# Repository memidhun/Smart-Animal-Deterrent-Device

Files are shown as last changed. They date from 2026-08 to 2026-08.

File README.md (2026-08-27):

# Automated Wildlife Monitoring & Deterrent System





An end-to-end, edge-AI powered wildlife monitoring and eco-friendly deterrence solution designed for forest-edge and agricultural borders. The system uses edge-optimized deep learning to detect wild animals in real time and triggers a non-lethal acetylene-gas combustion deterrent alongside long-range LoRa alerts.
<div align="center">
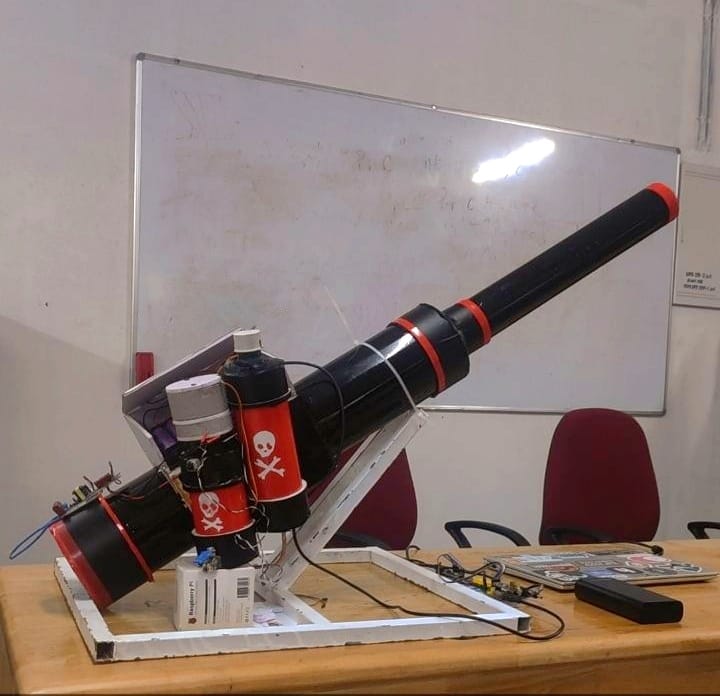
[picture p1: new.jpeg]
Prototype-Image
  
</div>

## Technical Highlights

* **Edge AI & Computer Vision:** Customs-trained **LoRa11n** (optimized YOLOv11n) running locally via NCNN engine on Raspberry Pi 4B.

* **Long-Range Wireless Stack:** Off-grid RF alerts over 3–5 km using LoRa SX1278 modules.

* **Automated Physical Deterrent:** Chemically generated Acetylene gas ($\text{CaC}_2 + 2\text{H}_2\text{O} \rightarrow \text{C}_2\text{H}_2 + \text{Ca(OH)}_2$) ignited via high-voltage spark to produce high-decibel acoustic and visual deterrents.

* **Off-Grid Power System:** Autonomous operation backed by a 12V solar panel and a 20,000 mAh Li-ion battery managed via BMS.

---

## Architecture & System Flow
<div align="center">
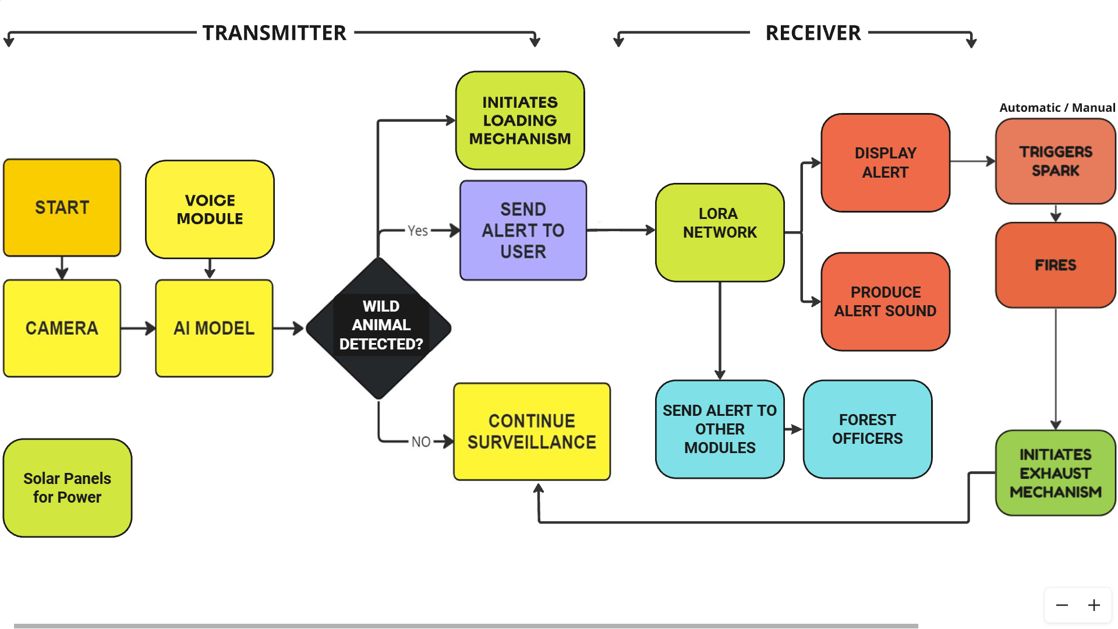
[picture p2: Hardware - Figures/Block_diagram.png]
Block Diagram
  
</div>

The system operates across a dual-unit topology to separate edge inference from high-power physical actuation.

```
┌─────────────────────────────────────────────────────────────────────────┐
│ TRANSMITTER UNIT (Detection Edge Node)                                  │
│ ┌───────────────┐     ┌───────────────┐     ┌─────────────────────────┐ │
│ │ USB Webcam    │ ──> │ Raspberry Pi  │ ──> │ LoRa11n Model (NCNN)    │ │
│ └───────────────┘     └───────────────┘     └────────────┬────────────┘ │
│                                                          │              │
│                                                  [Animal Detected?]     │
│                                                          │              │
│                                                 YES ┌────┴────┐         │
│                                                     │         │         │
│                                                     v         v         │
│                                              Peristaltic   LoRa SX1278  │
│                                              Water Pump    Transmitter  │
└──────────────────────────────────────────────────┬────────────┬─────────┘
                                                   │            │
                                  Chemical Feed    │            │ 433/868 MHz RF
                                  (Water + CaC2)   │            │ (3-5 km Range)
                                                   v            v
┌─────────────────────────────────────────────────────────────────────────┐
│ RECEIVER UNIT (Deterrent Actuator Node)                                 │
│                                              ┌────────────────────────┐ │
│                                              │ LoRa SX1278 Receiver   │ │
│                                              └───────────┬────────────┘ │
│                                                          │              │
│                                                          v              │
│ ┌───────────────┐     ┌───────────────┐     ┌─────────────────────────┐ │
│ │  High-Voltage │ <── │ Relay Module  │ <── │ ESP32 / Arduino Controller│ │
│ │ Spark Igniter │     └───────────────┘     └────────────┬────────────┘ │
│ └───────┬───────┘                                        │              │
│         │                                                v              │
│         v                                       ┌─────────────────┐     │
│  [Acoustic Blast                                │ TFT Display /   │     │
│   & Flash Light]                                │ Buzzer Alerts   │     │
│                                                 └─────────────────┘     │
└─────────────────────────────────────────────────────────────────────────┘

```

---

## Model Benchmark & Evaluation

Tested on a dataset of 15,000 annotated images across 5 classes (Elephant, Tiger, Monkey, Squirrel, Bat):

| Model | Accuracy (%) | mAP@0.5 (%) | Frame Rate (FPS on Pi 4B) |
| --- | --- | --- | --- |
| **LoRa11n (Proposed)** | **94.2%** | **94.1%** | **11.1 FPS** |
| YOLOv5-small | 91.5% | 90.8% | 7.1 FPS |
| EfficientDet-D0 | 89.0% | 88.2% | 5.2 FPS |
| SSD-MobileNet | 86.2% | 85.0% | 9.4 FPS |

---

## Hardware Assembly & Components

### Edge Processing & Sensors

* **Raspberry Pi 4B (4GB):** Primary AI inference engine.
* **ESP32 & Arduino Nano:** Real-time sensor input, UI driving (LVGL), and relay execution control.
* **LoRa SX1278 Modules:** Long-range wireless transceiver.
* **Sensors:** Water level sensors and HX711 weight sensors for automated material monitoring.

### Actuation & Combustion System

* **5V Peristaltic Pump:** Precise water dosing into the calcium carbide chamber.
* **24V Solenoid Valve:** Controls gas release into the ignition chamber.
* **High-Voltage Arc Generator:** Ignites accumulated acetylene gas mixture safely.

## 🧪 The Deterrent Mechanism

The system relies on an automated, controlled chemical reaction to produce a loud acoustic blast and flash, mimicking a gunshot without lethal projectiles. 

**Reaction Equation:**
`CaC₂ + 2H₂O → C₂H₂ (Acetylene Gas) + Ca(OH)₂`

When an animal is detected, the peristaltic pump drops water onto the solid calcium carbide. The resulting acetylene gas is contained until optimal pressure is reached, at which point the ESP32 triggers the high-voltage arc generator, combusting the gas.

---

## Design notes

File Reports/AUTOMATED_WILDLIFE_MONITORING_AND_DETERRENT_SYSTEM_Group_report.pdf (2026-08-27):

## AUTOMATED WILDLIFE MONITORING AND

## DETERRENT SYSTEM

PROJECT REPORT PHASE- II

submitted by

### MIDHUN MATHEW (MGP21UEC036)

### NEENA MATHEW (MGP21UEC039)

### SACHU RAJ (MGP21UEC049)

### SARIN C ROY (MGP21UEC050)

in partial fulfilment of the requirements

for the award of the degree of

BACHELOR OF TECHNOLOGY

### DEPARTMENT OF ELECTRONICS ENGINEERING

### SAINTGITS COLLEGE OF ENGINEERING (AUTONOMOUS)

### KOTTAYAM

### APRIL 2025

## CERTIFICATE

This is to certify that this report entitled AUTOMATED WILDLIFE MONITORING

AND DETERRENT SYSTEM is the bonafide record Major Project Report submitted

by MIDHUN MATHEW (MGP21UEC036), NEENA MATHEW (MGP21UEC039),

SACHU RAJ (MGP21UEC049), SARIN C ROY (MGP21UEC050) during the aca-

demic year 2024-2025 in partial fulfillment of the requirements for the award of the

Degree of Bachelor of Technology in Electronics and Communication Engineering

of the Saintgits College of Engineering (Autonomous) under the APJ Abdul Kalam

Technological University.

Er. Ashwin P V
Project Guide
Assistant Professor
Dept. of Electronics Engineering

Er. Ashly John
Project Co-ordinator
Assistant Professor
Dept. of Electronics Engineering

Dr. Sreekala K. S.
Associate Professor & Head Dept. of Electronics Engineering

Place: Kottayam

Date:

## ACKNOWLEDGEMENTS

We express our profound gratitude to all those who have supported us. Our sincere

thanks to:

ER. ASHWIN PV, under whose inspiring guidance and supervision this research was

carried out.His insistent attitude and timely help led to the successful completion of this

project.

ER. ASHLY JOHN, Major Project Coordinator, Saintgits College of Engineering (Au-

tonomous) for providing an excellent ambience that led to the completion of this work

on time.

DR. BEENA A O, Program Coordinator, for her encouragement and guidance.

DR. SREEKALA K.S, Head,Department of Electronics Engineering for providing all

departmental facilities.

DR. SUDHA T, Principal, Saintgits College of Engineering, Pathamuttom for provid-

ing the facilities environment to prepare and present this project.

All the staff and students of the Department of Electronics Engineering for rendering

help and support. Our parents, friends and well-wishers for their constant support and

timely help.

Above all we thank the Almighty God for His Grace and Blessings that made it

possible for us to complete this Project Phase-II successfully.

i

## ABSTRACT

KEYWORDS :- Wildlife Monitoring, Deep Learning, LoRa Communication, YOLO,

Human-Wildlife Conflict, Crop-Protection

Human-wildlife conflicts, particularly those that involve elephants, pose a significant

threat to agricultural communities and forest edge settlements. To address this issue,

an Automated Wildlife Monitoring and Deterrent System has been developed. The sys-

tem leverages deep learning-based object detection models, specifically an optimized

YOLOv11n network, to identify wildlife such as elephants, tigers, monkeys, squirrels,

and bats from live camera feeds. Upon detecting an animal, the system initiates a mul-

tilayered deterrence mechanism using a carbide-based acetylene gas generator that pro-

duces loud sounds and bright flashes to repel wildlife without causing harm. Real-time

alerts and system statuses are communicated to nearby residents and forest officials us-

ing LoRa wireless modules, ensuring timely intervention even in remote regions with

limited network connectivity. The entire setup is solar powered, enabling sustainable

and continuous operation. In addition, sensor modules ensure the safe and efficient

functioning of the acetylene generation mechanism. Compared to traditional methods

such as electric fencing and manual patrolling, the proposed system offers a more intel-

ligent, eco-friendly, and automated solution to mitigate human-wildlife conflicts.

ii

## TABLE OF CONTENTS

ABSTRACT | ii
LIST OF FIGURES | vii
1 INTRODUCTION | 1
2 LITERATURE SURVEY | 2

2.1 IoT-Based Animal Trespass Identification and Prevention System for

2.2 Wild Animals Intrusion Detection for Safe Commuting in Forest Corri-

2.4 Monitoring the Movements of Wild Animals and Alert System Using

2.5 Development of an Elephant Detection and Repellent System Based on

3 OBJECTIVES | 5
3.1 Development of an Automated Wildlife Monitoring System | 5
3.2 Implementation of an Eco-Friendly Deterrent Mechanism | 5
3.3 Integration of Long-Range, Low-Power Communication | 5
3.4 Deployment of Sustainable, Solar-Powered Infrastructure | 6

### 3.5 Real-Time System Monitoring and Maintenance Automa-

3.7 Contribution to Human-Wildlife Conflict Mitigation . . . | 6
4 METHODOLOGY | 7

iii

5 SYSTEM DESCRIPTION | 11
6 SOFTWARE DEVELOPMENT | 21

iv

7 RESULTS AND ANALYSIS | 26
8 CHALLENGES AND SOLUTIONS | 32
9 APPLICATIONS | 34

v

10 FUTURE SCOPE | 36
11 PROJECT TIMELINE | 38
12 CONCLUSION | 39

## LIST OF FIGURES

4.1 Block Diagram | | 7
5.1 Camera Module | | 11
5.2 Raspberry Pi 4B | | 12
5.3 ESP32 Microcontroller | | 12
5.4 LoRa SX1278 Module | | 13
5.5 Solar Panel and Battery Backup System | | 13
5.6 2.8-inch TFT Display Module | | 14
5.7 24V Solenoid Valve | | 14
5.8 Relay Module | | 15
5.9 5V Peristaltic Pump | | 15
5.10 Calcium Carbide | | 16
5.11 Water Level Sensor | | 16
5.12 YOLO v11 Architecture | | 17
5.13 Circuit Diagram - Transmitter | | 18
5.14 Circuit Diagram - Receiver | | 19
5.15 Prototype - Outdoor Version | | 20
5.16 Prototype - Portable Version | | 20
6.1 Dataset Samples | | 21
6.2 Dataset Labeling | | 23
6.3 Model Comparison | | 25
7.1 Dataset Distribution per Class | | 27
7.2 Accuracy vs Epoch | | 28
7.3 Loss vs Epoch | | 29
7.4 Confusion Matrix | | 29
7.5 FPS Comparison of Different Models | | 30
7.6 Comparison of Wireless Communication Protocols | | 31

vii

## CHAPTER 1

## INTRODUCTION

Human-wildlife conflicts, particularly those involving elephants and other large mam-

mals, have emerged as a serious concern for rural and forest-adjacent communities.

Traditional methods for preventing wildlife intrusions, such as manual patrolling, elec-

tric fencing, and the use of scare devices, often suffer from limited effectiveness, high

maintenance costs, and potential harm to both humans and animals. These methods

can also be labour-intensive, unreliable under varying environmental conditions, and

dependent on continuous human intervention. To address these challenges, there is a

growing need for intelligent, automated, and sustainable systems capable of detecting

wildlife intrusions in real-time and triggering effective non-lethal deterrent actions.

Recent advances in deep learning, particularly in real-time object detection models like

YOLOv11n, have opened new possibilities for automated wildlife monitoring. By de-

ploying edge-optimized AI models capable of accurately identifying various animal

species from live video feeds, it is possible to create proactive and responsive monitor-

ing systems that do not rely on manual surveillance.

Wireless communication technologies, such as LoRa, offer robust long-range data trans-

mission with minimal power consumption, making them ideal for deployment in remote

forest-edge regions. Integrating these technologies with intelligent wildlife detection

systems enables real-time alerts and activation of deterrent mechanisms, even in areas

with poor connectivity to the cellular network.

This project aims to develop a novel method for mitigating human-wildlife conflict

through an Automated Wildlife Monitoring and Deterrent System a carbide-based de-

terrent mechanism that produces loud sounds and flashes to safely repel the animals.

This approach has the potential to revolutionize conflict mitigation strategies, providing

an eco-friendly, low-cost, and scalable solution to protect farmland and human set-

tlements from wildlife intrusions. By promoting nonlethal deterrence and real-time

alerting, this system supports both conservation efforts and community safety, fostering

sustainable coexistence between humans and wildlife.

## CHAPTER 2

## LITERATURE SURVEY

## 2.1 IoT-Based Animal Trespass Identification and Pre-

## vention System for Smart Agriculture [1]

Manoharan S., Vignesh M., Ranjith R. “IoT-Based Animal Trespass Identification

and Prevention System for Smart Agriculture.” International Research Journal of

Engineering and Technology (IRJET) 7.5 (2020): 2395-0056.

Wildlife intrusion into agricultural lands causes significant damage to crops and prop-

erty. In this paper, an IoT-based system is proposed to prevent animal intrusions using

motion sensors, thermal imaging, and AI-based classification. While the system pro-

vides real-time alerts to farmers, a major limitation is its dependency on external net-

work connectivity and continuous power supply, which restricts deployment in remote

areas. Our project addresses these challenges by employing a solar-powered, low-power

wide-area communication (LoRa) based architecture, ensuring uninterrupted operation

in off-grid environments with minimal energy requirements.

## 2.2 Wild Animals Intrusion Detection for Safe Commut-

## ing in Forest Corridors Using AI Techniques [2]

Ashwini J., Anandhi S. “Wild Animals Intrusion Detection for Safe Commuting

in Forest Corridors Using AI Techniques.” International Journal of Engineering

Research Technology (IJERT), vol. 10, no. 11, 2021.

This study proposes the use of AI-based image recognition models to detect wild an-

imals in forest corridors, aimed at preventing accidents. However, reliance on pre-

installed fixed surveillance cameras limits the system’s coverage and real-time effec-

tiveness due to environmental obstructions. In contrast, our system incorporates mobile and strategically placed camera modules combined with real-time edge computing, en-

abling wider surveillance with higher adaptability even in dynamically changing forest

and farmland environments.

## 2.3 IoT-Based Smart Farmland Using Deep Learning

[3]

Neha K. Chaurasia, Sushma B. “IoT-Based Smart Farmland Using Deep Learn-

ing.” International Journal of Engineering Research Technology (IJERT), vol. 9, no.

6, 2020.

An IoT-based security solution for farmlands using deep learning is proposed in this

study, employing CNNs for animal detection and activating static sound deterrents.

However, static deterrents tend to lose effectiveness over time due to animal habitua-

tion. Our project overcomes this by implementing a dynamic, carbide-based acetylene

deterrent mechanism that generates unpredictable loud sounds and flashes, reducing the

likelihood of animals adapting and ensuring sustained deterrent effectiveness.

## 2.4 Monitoring the Movements of Wild Animals and

## Alert System Using Deep Learning Algorithm [4]

K. Anusha, P. Gnanaprakasam, A. Kalaiselvi “Monitoring the Movements of Wild

Animals and Alert System Using Deep Learning Algorithm.” International Journal

of Research in Engineering, Science and Management (IJRESM), vol. 4, no. 8, 2021.

This paper discusses real-time monitoring systems utilizing deep learning algorithms

for animal detection. However, cloud-based AI processing introduces latency and ne-

cessitates constant network availability, limiting its application in rural settings. Our

project circumvents these limitations by deploying lightweight, edge-optimized AI mod-

els such as YOLOv11n directly on embedded devices like Raspberry Pi, enabling offline

processing with minimal latency and immediate activation of deterrent mechanisms

without dependency on cloud servers.

## 2.5 Development of an Elephant Detection and Repel-

## lent System Based on EfficientDet-Lite Models [5]

P. Prakash, R. Ashok Kumar, V. Sriram, S. Srikanth “Development of an Elephant

Detection and Repellent System Based on EfficientDet-Lite Models.” International

Research Journal of Engineering and Technology (IRJET), vol. 8, no. 6, 2021.

In this study, an EfficientDet-Lite-based model was utilized for elephant detection, cou-

pled with pre-recorded sound-based deterrence. While effective initially, static audio

deterrents may lead to animal desensitization over time. Our project proposes a more ro-

bust solution by combining real-time wildlife detection with a physical deterrent mech-

anism involving controlled acetylene gas ignition to produce loud acoustic and visual

stimuli. This method increases unpredictability, enhancing long-term deterrence with-

out harming the animals.

## CHAPTER 3

## OBJECTIVES

### 3.1 Development of an Automated Wildlife Monitoring System

The project aims to design and develop a fully automated wildlife monitoring system

capable of real-time detection and classification of wild animals, particularly elephants,

using optimized deep learning models. By leveraging computer vision techniques and

wide-angle surveillance cameras, the system ensures continuous observation of vulner-

able agricultural and forest-border regions.

### 3.2 Implementation of an Eco-Friendly Deterrent Mechanism

A key objective of the system is to implement a non-lethal, reusable deterrent mech-

anism utilizing a carbide-based acetylene gas generation process. Upon detection of

wildlife intrusions, the system automatically activates the deterrent, producing loud

sounds and bright flashes to scare away animals without inflicting harm. This approach

promotes humane wildlife management practices and reduces the need for traditional

hazardous methods like electric fencing or chemical repellents.

### 3.3 Integration of Long-Range, Low-Power Communication

To ensure real-time alerting and coordination, the project integrates LoRa-based wire-

less communication technology. This long-range, low-power system enables efficient

transmission of alerts and system status updates across several kilometers, even in re-

mote areas with limited or no mobile network coverage. The use of LoRa ensures

timely notification to farmers, residents, and forest officials, facilitating prompt human

intervention when necessary.

### 3.4 Deployment of Sustainable, Solar-Powered Infrastructure

Recognizing the challenges of deploying electronic systems in remote and forested ar-

eas, the project prioritizes the use of solar-powered energy solutions. The system is de-

signed to operate autonomously with minimal maintenance, utilizing solar panels and

battery backup to ensure uninterrupted functioning. Energy-efficient hardware design

and low-power operation modes further contribute to sustainability, enabling continu-

ous 24/7 operation even during adverse weather conditions.

### 3.5 Real-Time System Monitoring and Maintenance Automation

The system incorporates sensor modules such as HX711 weight sensors and water level

detectors to monitor the critical resources required for acetylene production. Auto-

mated monitoring ensures timely refilling of materials and prevents operational down-

time. Alerts related to low resource levels are automatically communicated to the user,

minimizing the need for manual inspection and reducing system maintenance efforts.

### 3.6 Field Validation and Performance Optimization

An essential objective is the rigorous field testing and validation of the system across

multiple agricultural zones prone to wildlife intrusions. Performance metrics such as

detection accuracy, latency, wireless communication reliability, and energy consump-

tion are systematically evaluated to refine the system for real-world deployment. The

goal is to achieve high detection precision, minimal response delays, and maximum

deterrent effectiveness under varied environmental conditions.

### 3.7 Contribution to Human-Wildlife Conflict Mitigation

The system not only protects human lives and agricultural resources but also promotes

wildlife conservation by using humane deterrence methods. Long-term, it seeks to

foster peaceful coexistence between human settlements and wildlife habitats.

## CHAPTER 4

## METHODOLOGY

The proposed system is designed for real-time detection and deterrence of wild animals

in forest-edge or agricultural areas. It integrates edge-based AI, long-range wireless

communication, and automated deterrent mechanisms powered sustainably through so-

lar energy. The methodology is structured around a two-stage architecture comprising

a Transmitter Unit and a Receiver Unit, each responsible for a defined sequence of

operations.

## 4.1 Block Diagram

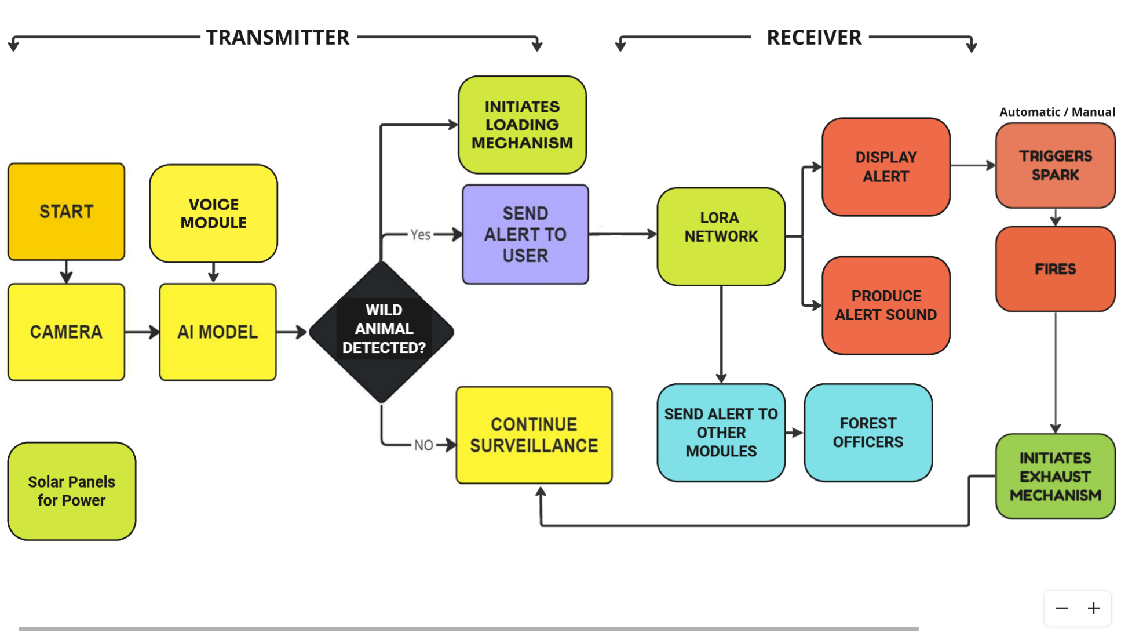
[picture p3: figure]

Figure 4.1: Block Diagram

### 4.1.1 Transmitter Unit

The transmitter unit forms the core of the detection system. It begins operation when

powered on via solar panels connected to a 12V battery and managed using a Battery

Management System (BMS) to ensure uninterrupted performance in outdoor environ-

ments. Upon initiation, a camera module connected to a Raspberry Pi 4B captures

real-time images or video. These inputs are immediately processed by a YOLO-based

deep learning model deployed locally on the Raspberry Pi. This lightweight convolu-

tional neural network has been trained on a custom dataset with five wildlife classes:

elephant, tiger, monkey, squirrel, and bats. The use of edge-based inference reduces

latency and eliminates the need for internet connectivity, a crucial feature for remote

environments.

To complement visual detection, a voice module embedded within the transmitter can

issue audible warnings when the system is activated, both to deter animals and alert

nearby humans. Once an animal is detected, a control logic block evaluates the model’s

output. If a wild animal is identified, the system initiates multiple parallel operations.

First, it triggers a mechanism that begins preparing the deterrent response. This includes

activating a peristaltic pump to fill a carbide chamber with water, allowing acetylene gas

to be produced for later ignition. Simultaneously, an alert is sent via the LoRa (Long

Range) wireless communication module to the receiver unit. The LoRa SX1278 mod-

ule is selected for its ability to transmit low-power RF signals over several kilometres,

making it ideal for covering vast agricultural or forest boundaries. If no animal is de-

tected, the system simply continues to monitor the environment in surveillance mode,

thereby conserving energy and system resources.

### 4.1.2 Receiver Unit

The receiver unit is responsible for alert dissemination, deterrent activation, and further

system escalation. Upon receiving a signal from the transmitter via LoRa, the ESP32

microcontroller processes the data and triggers a series of alerts. A buzzer module gen-

erates a loud warning sound, and a connected LCD display provides visual status in-

formation, informing users or nearby personnel of the threat. The system supports both

automatic and manual operation modes, allowing users to intervene when necessary.

In automatic mode, the receiver triggers a high-voltage spark mechanism to ignite the

acetylene gas mixture that was earlier prepared. This ignition produces a loud blast

intended to startle and repel animals from the protected area. Following this action, the system activates an exhaust mechanism to safely disperse any remaining gases from the

firing chamber, ensuring it is safe and ready for the next cycle.

In parallel, the receiver system can forward the alert to other critical endpoints, such as

mobile devices used by forest officers or secondary deterrent modules placed in nearby

zones. This multi-node alert system ensures that authorities are promptly informed and

that wildlife deterrence is applied over a wider area, enhancing the overall effectiveness

of the solution..

### 4.1.3 Data Acquisition and Analysis

Capturing movement data and images from the sensors and analyzing them locally us-

ing lightweight machine learning models. This step ensures quick, efficient identifica-

tion of wildlife presence without relying heavily on cloud computation.

### 4.1.4 Wireless Communication

Using LoRa technology to transmit detection alerts over long distances to a centralized

monitoring system or directly to deterrent devices. This provides reliable communica-

tion even in remote or difficult terrains.

### 4.1.5 Machine Learning Model Development

Training machine learning models to classify detected movement patterns and images

as wildlife or non-wildlife entities. Utilizing supervised learning with labeled data to

improve model performance and reduce false positives.

### 4.1.6 Deterrent Activation

Upon positive detection of a wild animal, the system activates a carbide-based deter-

rence mechanism designed to produce a loud acoustic burst to scare away intruding

animals. This method leverages the chemical reaction between calcium carbide (CaC2)

and water to generate acetylene gas (C2H2). In the transmitter unit, a PVC chamber is

used as a reaction vessel where a measured amount of calcium carbide is placed. Once detection is confirmed, a DC-powered peristaltic pump dispenses a controlled volume

of water into this chamber, initiating the reaction:

CaC2 + 2H2O → C2H2 + Ca(OH)2 | (4.1)

The resulting acetylene gas accumulates within the sealed chamber until a spark, gen-

erated via a high-voltage ignition module, ignites the gas-air mixture. This ignition

produces a sudden and loud combustion sound, which serves as an effective deterrent

to large animals such as elephants and wild boars.

### 4.1.7 Integrated Power and Energy Efficiency

To ensure uninterrupted performance in remote locations, the entire system is powered

using solar energy. A 12V solar panel charges a 20,000 mAh lithium-ion battery, which

powers both the Raspberry Pi and ESP32 microcontrollers. A smart Battery Manage-

ment System (BMS) regulates charging, prevents over-discharge, and supports system

longevity. This design eliminates dependence on external power infrastructure and pro-

vides resilience against environmental challenges.

### 4.1.8 Advantages Over Traditional Approaches

Unlike manual patrolling or fixed noise deterrents, the proposed methodology offers

intelligent, automated detection and deterrence with minimal human input. It operates

continuously, adapts to real-time wildlife presence, and scales easily across large ter-

rain. The use of solar power, LoRa-based communication, and embedded AI processing

ensures that the system is not only sustainable but also cost-effective, accurate, and re-

liable. Its modular design allows further expansion or replication across critical zones

prone to wildlife conflict.

## CHAPTER 5

## SYSTEM DESCRIPTION

The system integrates modern embedded hardware and intelligent software to detect the

presence of wildlife and activate deterrent mechanisms in real-time. Hardware compo-

nents include a camera module, a Raspberry Pi processing unit, LoRa communication

modules, a solar-powered energy setup, and a carbide-based deterrent mechanism. Soft-

ware components such as an optimized deep learning model (YOLOv11n), real-time

video processing tools (OpenCV), and wireless communication protocols enable effi-

cient animal detection, alert generation, and deterrent activation.

## 5.1 Hardware Specifications

### 5.1.1 Camera Module (USB Webcam)

Captures real-time video feeds from the monitored environment with high-resolution

and wide-angle capabilities. The camera acts as the primary sensory input, providing

the necessary image data for wildlife detection, even in low-light conditions with in-

frared capability if needed.

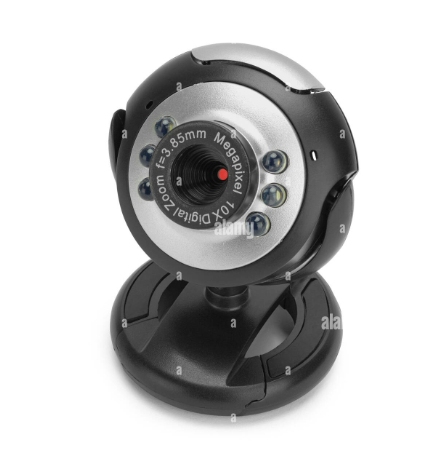
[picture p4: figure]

Figure 5.1: Camera Module

### 5.1.2 Raspberry Pi 4B

Serves as the main processing unit responsible for running the deep learning inference

model (YOLOv11n) and controlling the overall system operation. It manages real-time

image processing, decision making, communication handling, and deterrent activation

processes.

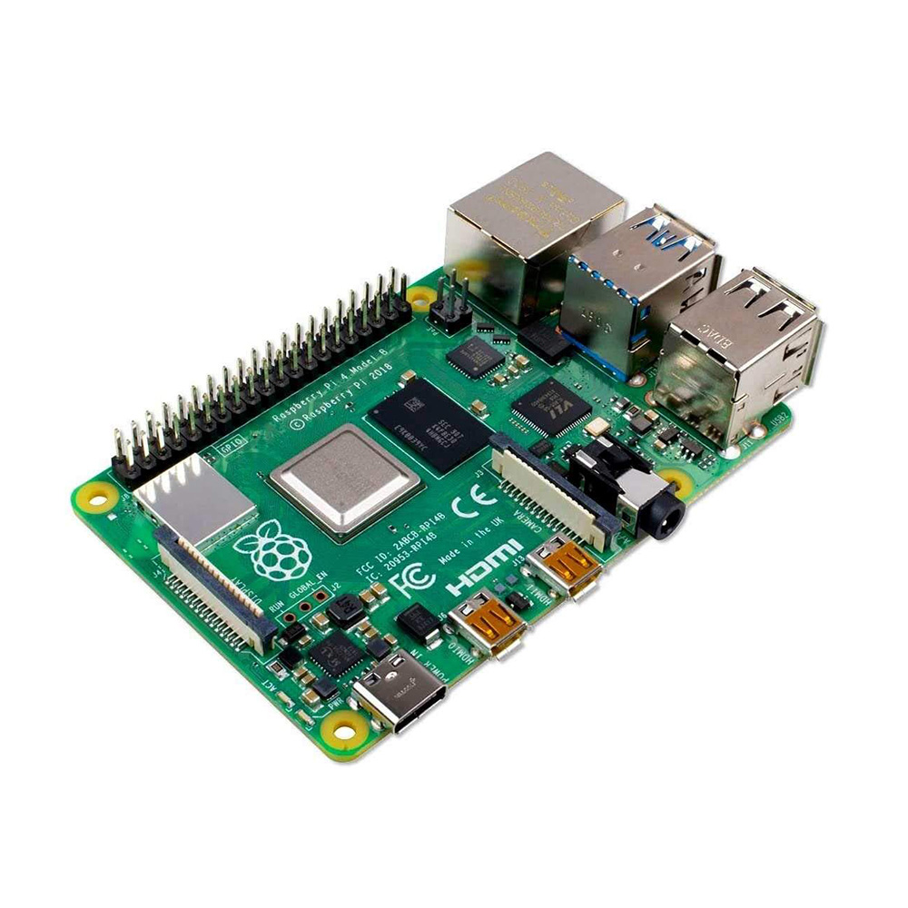
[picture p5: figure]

Figure 5.2: Raspberry Pi 4B

### 5.1.3 ESP32 Microcontroller

Acts as the central control unit responsible for coordinating all hardware components,

including sensors, actuators, display, and communication modules. With built-in Wi-

Fi, Bluetooth, and multiple GPIOs, the ESP32 efficiently manages data acquisition,

LoRa communication, and output control. Its high processing speed and low power

consumption make it ideal for real-time embedded applications in field environments.

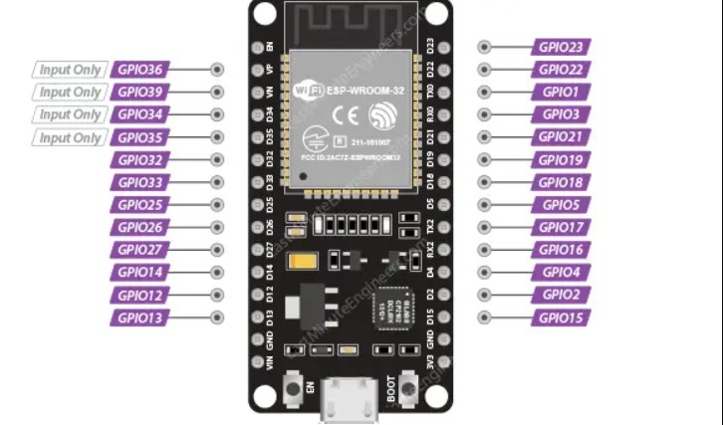
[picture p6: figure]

Figure 5.3: ESP32 Microcontroller

### 5.1.4 LoRa SX1278 Module

Ensures long-range, low-power wireless communication between the transmitter (de-

tection unit) and the receiver (deterrent unit). It allows the transmission of alerts and

system status messages over several kilometers, making it ideal for remote and forested

areas with poor cellular connectivity.

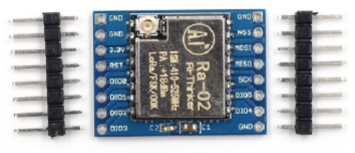
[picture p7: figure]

Figure 5.4: LoRa SX1278 Module

### 5.1.5 Solar Panel and Battery Backup System

Provides continuous, renewable energy to power the system components. The solar

panel charges a high-capacity lithium-ion battery that ensures the system’s uninter-

rupted operation during nighttime or cloudy weather, promoting off-grid sustainability.

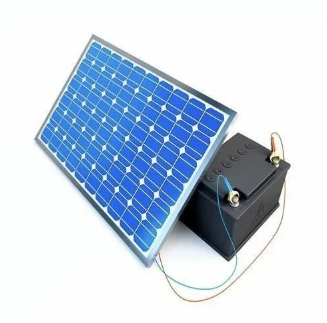
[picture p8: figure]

Figure 5.5: Solar Panel and Battery Backup System

### 5.1.6 TFT Display Module

Provides a user-friendly graphical interface for visualizing detection results, system

status, and real-time alerts. With its high-resolution display and wide viewing angle,

it enables effective monitoring even in outdoor conditions. The display, driven by the

ESP32 using the LVGL graphics library, supports intuitive UI layouts for field deploy-

ment.

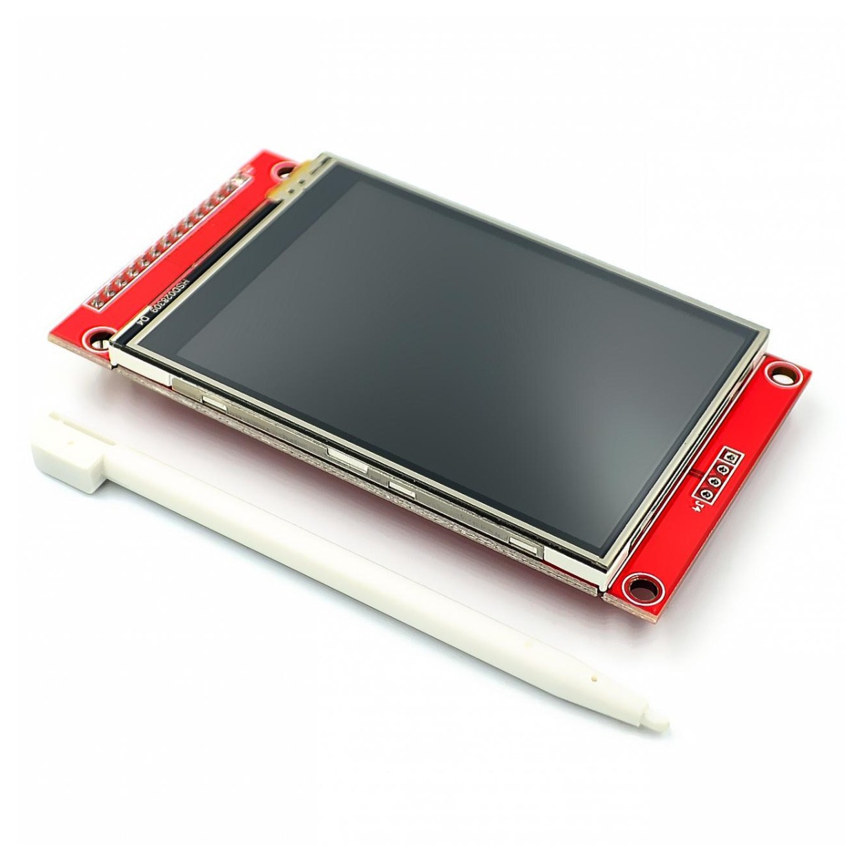
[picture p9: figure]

Figure 5.6: 2.8-inch TFT Display Module

### 5.1.7 Solenoid Valve

Controls the release of pressurized water or gas in response to detected wildlife pres-

ence. It is activated by the ESP32 to serve as part of the deterrent mechanism, creating

sudden bursts of fluid to scare away animals. The valve operates reliably on a 24V

power supply, offering fast switching, low power draw, and rugged performance suit-

able for outdoor conditions.

Figure 5.7: 24V Solenoid Valve

### 5.1.8 Relay Module

Acts as a crucial control interface between the ESP32 and high-voltage components

such as the plasma ignition system and the peristaltic pump. It allows the microcon-

troller to safely switch these high-power devices by providing electrical isolation and

precise activation timing. The relay ensures reliable operation of the ignition mecha-

nism and water pumping process essential for acetylene gas generation and controlled

ignition.

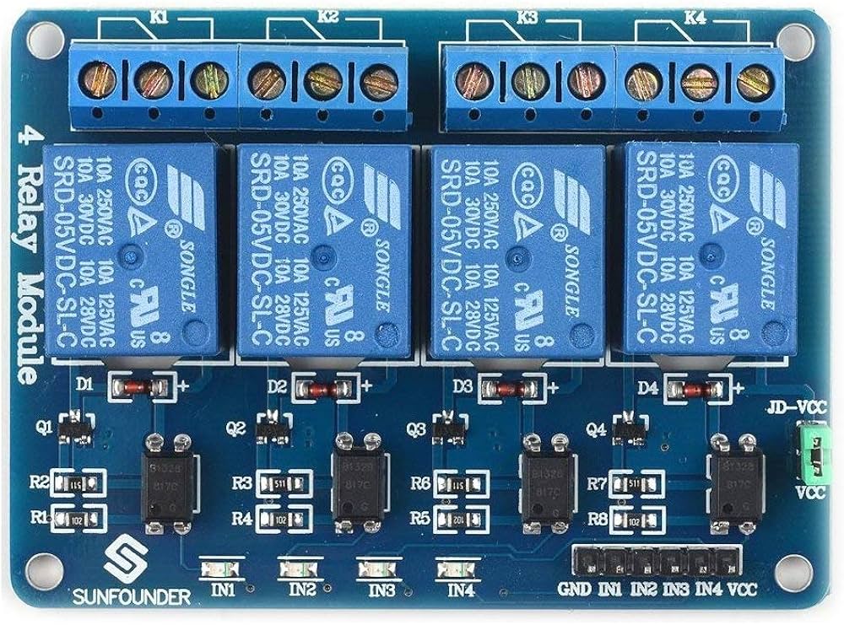
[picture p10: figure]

Figure 5.8: Relay Module

### 5.1.9 5V Peristaltic Pump

Used to deliver controlled amounts of water into the reaction chamber for carbide-based

gas generation. The pump ensures safe and precise fluid transfer without contamination,

thanks to its tubing-based mechanism. Operating at 5V, it is energy-efficient and ideal

for low-flow applications, making it suitable for field deployments where accuracy and

reliability are essential.

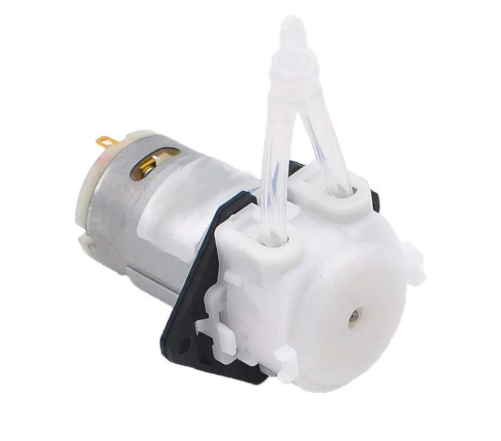
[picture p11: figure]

Figure 5.9: 5V Peristaltic Pump

### 5.1.10 Carbide-Based Deterrent Mechanism

Uses a chemical reaction between calcium carbide and water to produce acetylene gas,

which is ignited to generate loud explosion-like sounds and bright flashes. This non-

lethal, eco-friendly method effectively deters wildlife without causing harm to animals

or the environment.

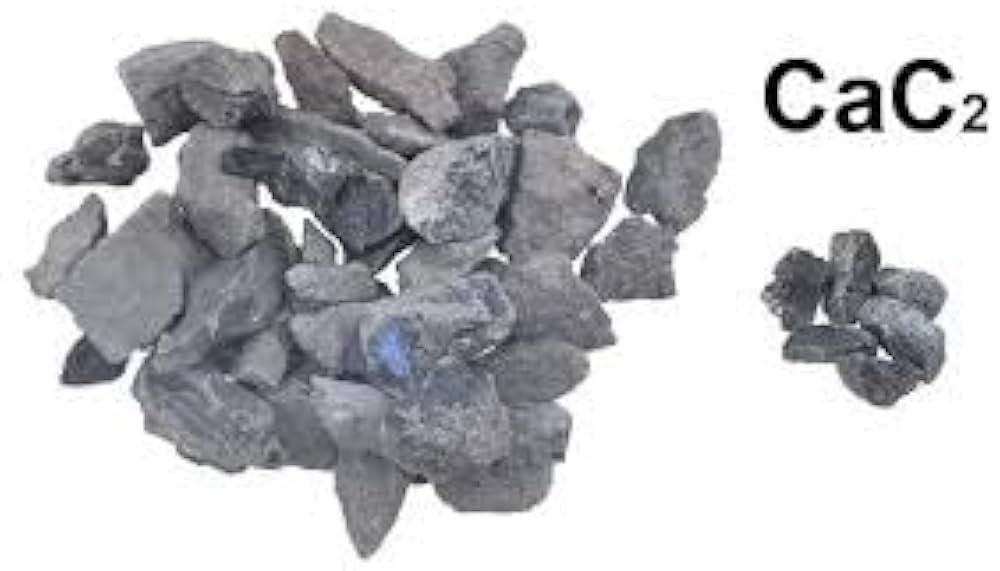
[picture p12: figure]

Figure 5.10: Calcium Carbide

### 5.1.11 Sensors

Monitor the availability of water and acetylene production in the deterrent module.

These sensors automate maintenance alerts, ensuring consistent system operation and

preventing failure due to resource depletion.

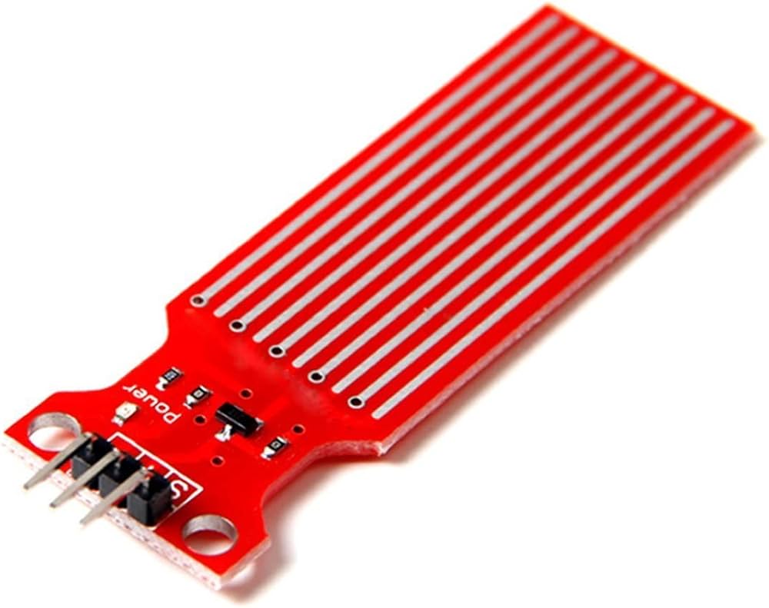
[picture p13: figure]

Figure 5.11: Water Level Sensor

## 5.2 Software Specifications

### 5.2.1 Deep Learning Model (YOLOv11n)

The system utilizes a customized YOLOv11n object detection model, optimized for

real-time animal detection on resource-constrained hardware. The model is trained on a dataset comprising images of elephants and other wildlife, achieving high detection

accuracy while maintaining low computational overhead. Inference is performed using

the NCNN framework to maximize efficiency on the Raspberry Pi 4B.

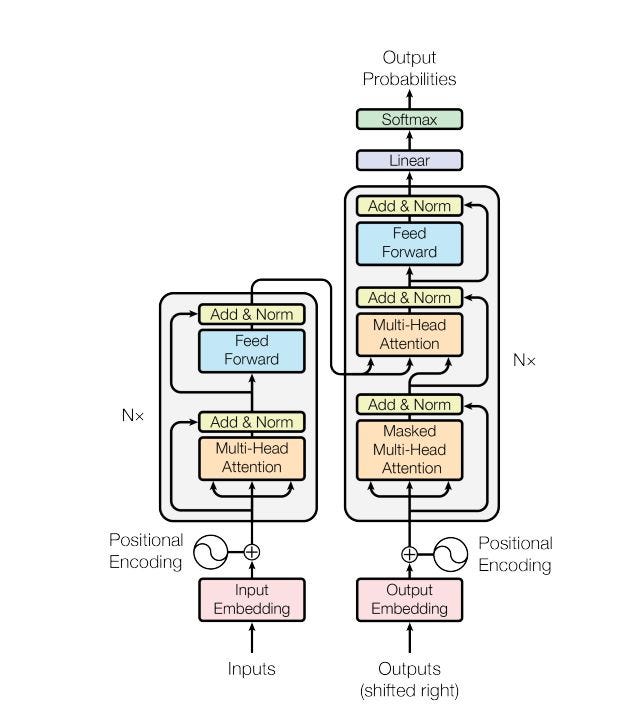
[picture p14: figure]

Figure 5.12: YOLO v11 Architecture

### 5.2.2 Real-Time Image Processing (OpenCV)

OpenCV libraries are employed for real-time video frame capture, preprocessing, and

handling image data streams. The captured frames are resized, normalized, and fed into

the YOLOv11n model for object detection. OpenCV also facilitates annotation and

visualization of detection results on the output frames.

### 5.2.3 Wireless Communication Stack (LoRa)

LoRa communication libraries are used to transmit wildlife detection alerts and system

status messages from the transmitter (camera and processing unit) to the receiver (de-

terrent module) and to the user alerting systems. The system ensures robust and reliable

communication over long distances, critical for real-world deployment in forested and

remote areas.

### 5.2.4 Alert Generation and Deterrent Activation Logic

Upon successful detection of wildlife, the system triggers an alert transmission via

LoRa. At the receiver end, a microcontroller (ESP32 or similar) processes the received

alert and activates the deterrent system. Visual and acoustic deterrents are triggered

sequentially to ensure maximum effectiveness. The activation logic includes safety

checks, timeout management, and fallback handling to prevent accidental triggering.

### 5.2.5 Power Management and Energy Optimization

Software modules monitor the energy status using voltage sensing techniques. The

Raspberry Pi and LoRa modules are configured with sleep and wake-up cycles to mini-

mize energy consumption during idle periods. Battery levels are monitored, and appro-

priate alerts are sent if critical low battery levels are detected.

### 5.2.6 Circuit Diagram - Transmitter (Detection Unit)

A lightweight deep learning model (LoRa11n) runs on the Pi to process live video feeds

and perform real-time inference. Upon detecting a target animal, the unit sends a wire-

less alert signal using the LoRa SX1278 module, ensuring long-range and low-power

communication to the receiver side. This unit is powered by a regulated power supply

and includes an ESP32 microcontroller for coordination and fallback communication.

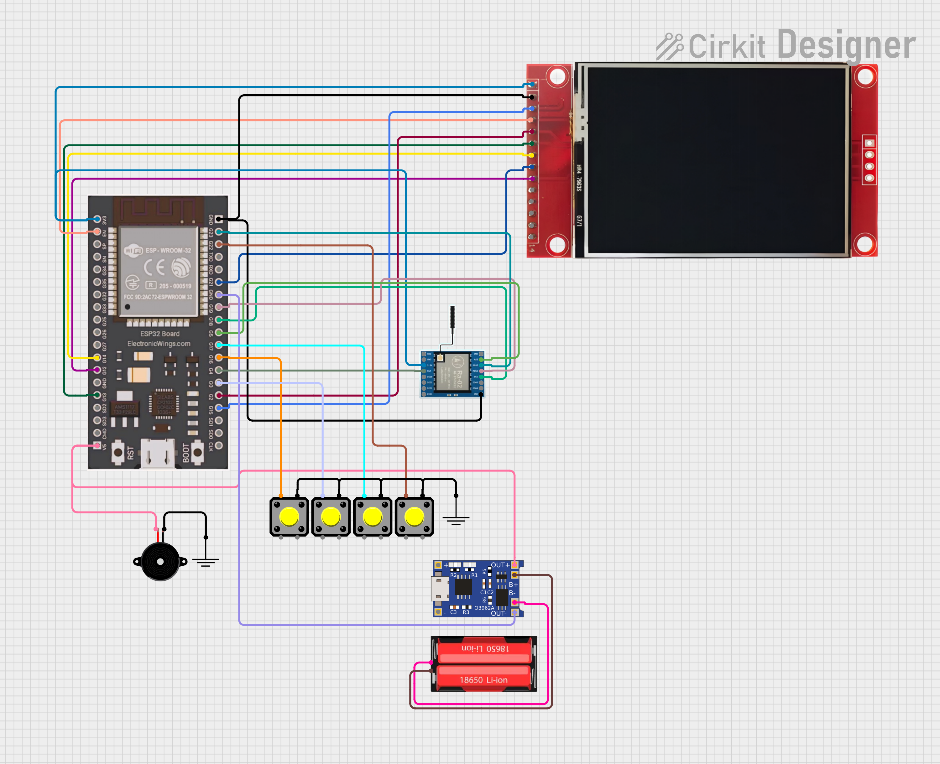
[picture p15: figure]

Figure 5.13: Circuit Diagram - Transmitter

### 5.2.7 Receiver Side (Deterrent Activation Unit)

The receiver unit is strategically positioned at a remote deterrent system and is equipped

with an Arduino Nano and LoRa SX1278 module. Upon receiving a signal from the

transmitter, the Arduino triggers a sequence of deterrent mechanisms. These include

activating a 5V peristaltic pump to inject water into a reaction chamber, followed by a

solenoid valve that releases carbide to produce acetylene gas. A relay module controls

the ignition system (e.g., a plasma arc igniter), creating a loud sound or flash to drive

animals away. This unit operates autonomously and reacts instantly to incoming alerts.

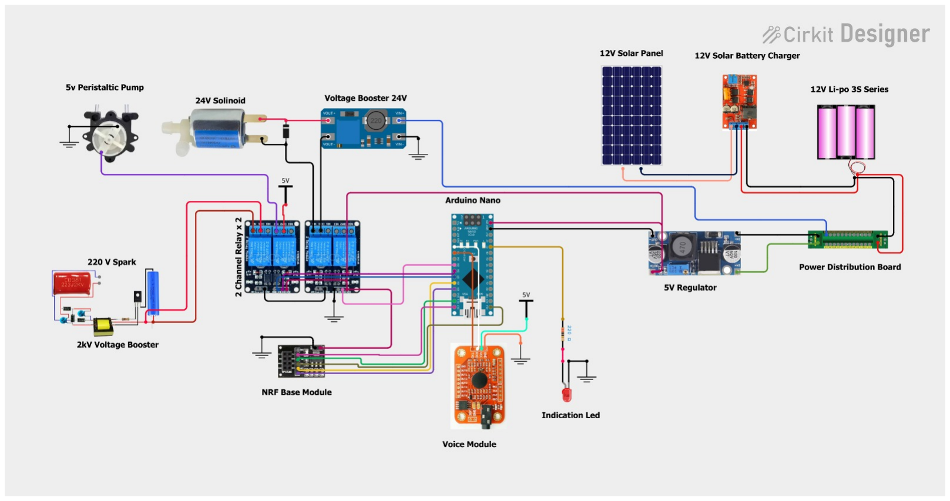
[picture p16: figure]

Figure 5.14: Circuit Diagram - Receiver

### 5.2.8 Mechanical Structure and Assembly

The mechanical assembly forms the physical foundation of the deterrent unit, integrat-

ing all key components into a functional structure. At the core lies a robust metallic

reaction chamber designed to handle gas buildup and ignition pressure safely. A 5V

peristaltic pump is connected to a water reservoir to inject precise amounts of water

into the carbide holding area. A 24V solenoid valve is positioned beneath the carbide

compartment to release acetylene gas into the ignition chamber upon activation. Sup-

porting structures include metal piping for fluid and gas transport, mounting plates for

the ESP32 controller and relay modules, and protective casings to shield electronics

from weather conditions. The ignition system—powered through a relay—is housed

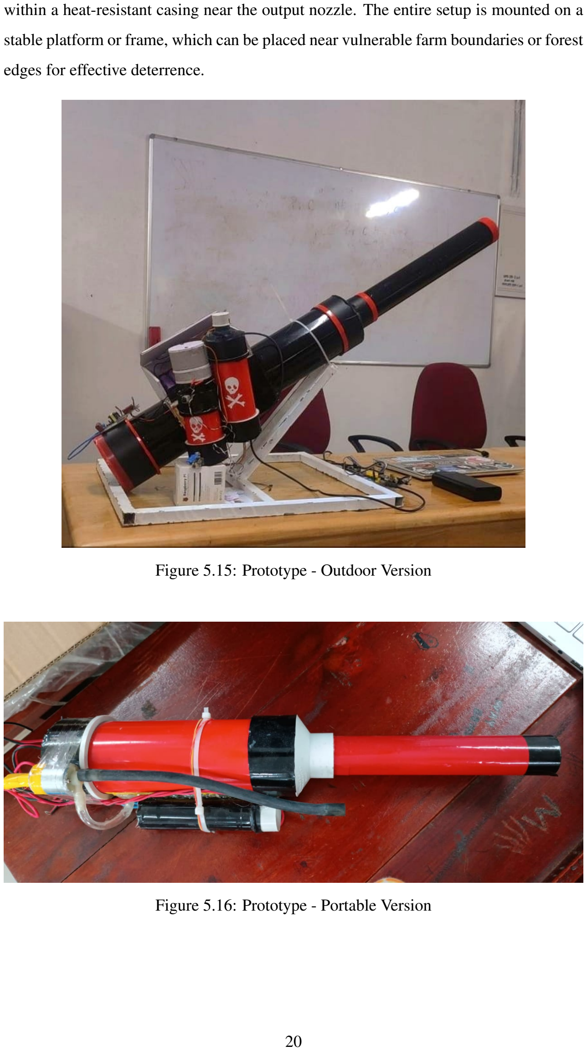
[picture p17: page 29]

within a heat-resistant casing near the output nozzle. The entire setup is mounted on a

stable platform or frame, which can be placed near vulnerable farm boundaries or forest

edges for effective deterrence.

Figure 5.15: Prototype - Outdoor Version

Figure 5.16: Prototype - Portable Version

## CHAPTER 6

## SOFTWARE DEVELOPMENT

## 6.1 Dataset Collection

### 6.1.1 Samples

This project involved collecting a diverse set of wildlife images to train and validate the

detection system. The dataset included:

– Wild Animals: Elephants, tigers, monkeys, squirrels, and bats.

– Other Objects: Humans, domestic animals (e.g., cows, dogs) to ensure proper

classification and avoid false positives.

– Environmental Conditions: Daytime, nighttime, fog, rain, and varying lighting

conditions.

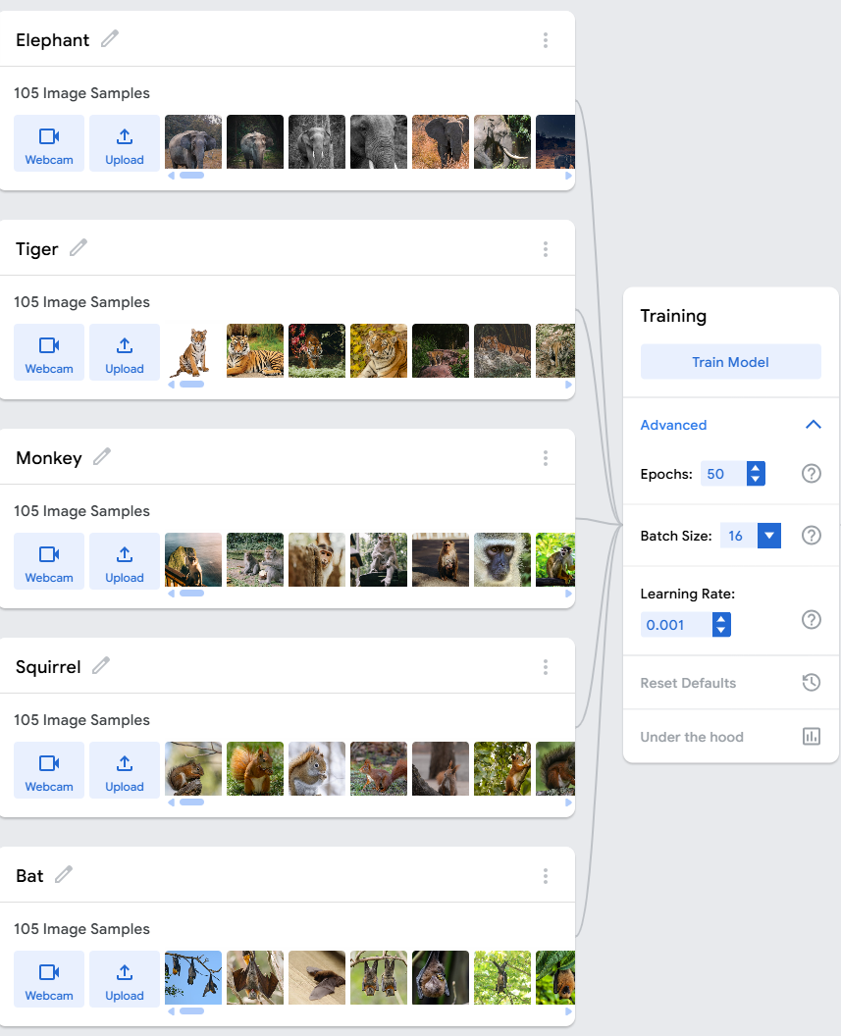
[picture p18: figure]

Figure 6.1: Dataset Samples

A total of approximately 15,000 images were collected and annotated with bounding

boxes and segmentation masks. The dataset was partitioned into 80% for training, 10%

for validation, and 10% for testing.

## 6.2 Machine Learning Analysis

The following deep learning models were explored for wildlife detection:

1. YOLOv5-small
2. EfficientDet-D0
3. SSD-MobileNet
4. Lora11n (proposed model based on YOLOv11n optimization)

The proposed Lora11n model demonstrated superior detection accuracy and infer-

ence speed on embedded platforms and was selected for final deployment.

## 6.3 Data Preprocessing

1) Library Import: Essential libraries such as PyTorch, NCNN, and OpenCV

were imported to facilitate model training, optimization, and real-time video pro-

cessing.

2) Dataset Preparation: Wildlife images were resized and normalized to standard

input dimensions. Data augmentation techniques like random flipping, rotation,

and color jittering were applied to enhance model generalization.

3) Annotation Processing: Bounding box annotations and segmentation masks

were parsed and reformatted for YOLOv11n training requirements.

4) Data Splitting: The dataset was stratified and split into training, validation, and

test sets to ensure balanced representation across animal classes.

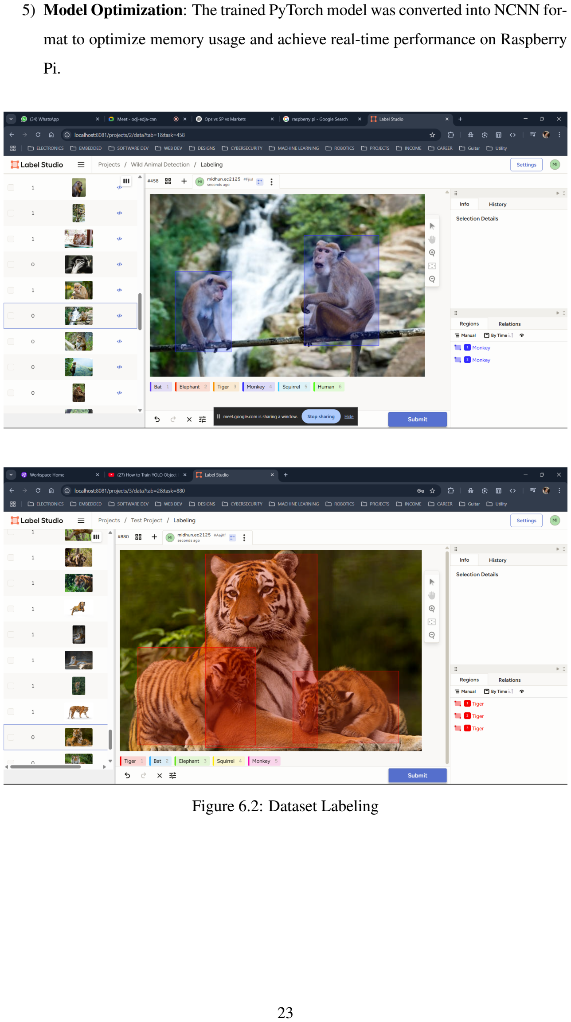
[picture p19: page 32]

5) Model Optimization: The trained PyTorch model was converted into NCNN for-

mat to optimize memory usage and achieve real-time performance on Raspberry

Pi.

Figure 6.2: Dataset Labeling

## 6.4 Testing and Training the Models

Once the dataset was prepared, the deep learning models were trained and evaluated

using standard performance metrics: mAP@0.5, Precision, Recall, F1-Score, and FPS

(Frames Per Second). The evaluation was carried out on the Raspberry Pi 4B hardware

to ensure practical deployability.

### 6.4.1 Yolo11n Model Evaluation

The Lora11n model achieved a detection accuracy of 94.2%, with a mean average preci-

sion (mAP@0.5) of 94.1%. It successfully detected elephants and other target animals

in real-time at an average inference speed of 11.1 FPS on Raspberry Pi 4B, ensuring

rapid and effective deterrent activation.

### 6.4.2 YOLOv5-small Model Evaluation

YOLOv5-small exhibited competitive detection accuracy but suffered from slower in-

ference (7.1 FPS) and higher resource usage, which could lead to thermal issues during

continuous operation.

### 6.4.3 EfficientDet-D0 Model Evaluation

Although EfficientDet-D0 provided good object detection capabilities, it struggled with

real-time performance on Raspberry Pi and exhibited latency, making it less suitable for

critical wildlife deterrence applications.

### 6.4.4 SSD-MobileNet Model Evaluation

SSD-MobileNet offered fast inference but lower detection accuracy, particularly under

low-light and occlusion scenarios. It was ruled out due to higher false negative rates.

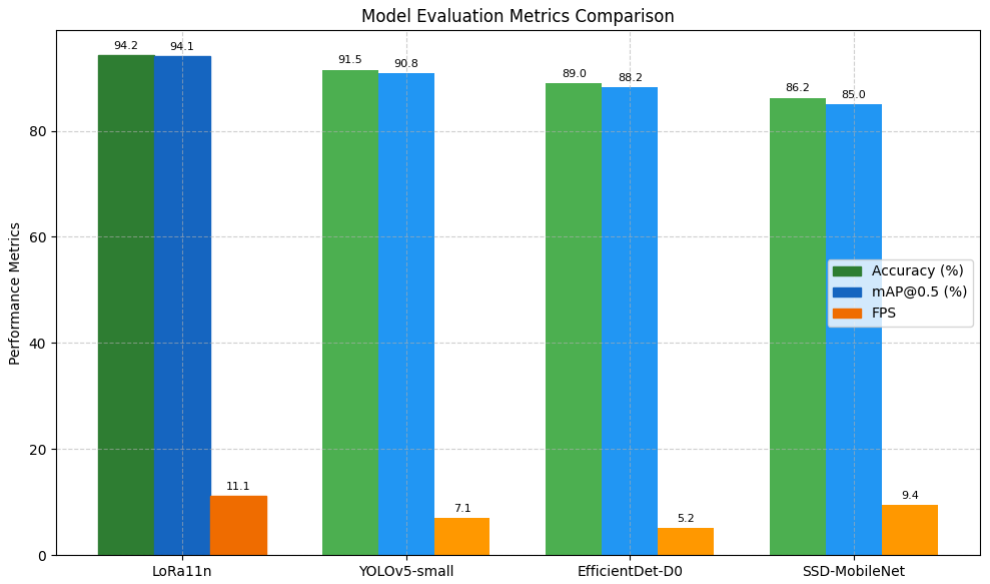
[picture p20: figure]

Figure 6.3: Model Comparison

## 6.5 Real-Time Testing and Deployment

The complete system was tested in field deployments across agricultural zones near

Konni and Idukki, areas with frequent elephant movement. The camera module cap-

tured real-time frames, and detection outputs triggered wireless alerts and deterrent ac-

tivations. After model deployment, real-time predictions were generated directly from

incoming video frames. When a wild animal (e.g., elephant) was detected, the system:

– Sent an immediate alert through LoRa to the remote receiver module.

– Triggered the visual and acoustic deterrent mechanisms.

– Displayed detection results on the monitoring GUI.

– Logged the detection event with timestamp and location metadata.

The seamless operation of detection, communication, and deterrence validated the

real-world applicability and robustness of the system in mitigating human-wildlife con-

flicts.

## CHAPTER 7

## RESULTS AND ANALYSIS

This section presents the comprehensive performance evaluation of the proposed Auto-

mated Wildlife Monitoring and Deterrent System. The results incorporate both quan-

titative and qualitative metrics to assess the machine learning model’s performance,

system latency, wireless communication efficiency, and deployment robustness in real-

time field scenarios. Evaluation has been based on the system’s accuracy, reliability,

and scalability under varied field conditions using metrics widely accepted in machine

learning and embedded deployment contexts.

## 7.1 Experimental Setup

The system was deployed with the following hardware and software:

- Hardware: Raspberry Pi 4B (64-bit, 4GB RAM), LoRa SX1278 RF Module,

USB Webcam (720p, 30FPS), Solar-powered battery, Solenoid carbide deterrent.

- Software: Anaconda for model training, NCNN for model inference, OpenCV

for image processing, Label-Studio for dataset annotation.

Deployment zones included three farms in Konni and one site in Idukki. Field testing

lasted for two weeks under varied environmental conditions.

## 7.2 Dataset Description

A balanced dataset was curated with five target animal classes:

- Elephant
- Tiger

- Monkey
- Squirrel
- Bats

Each class contained 3,000 images, making a total of 15,000 annotated samples. Data

was split in an 80:10:10 ratio for training, validation, and testing.

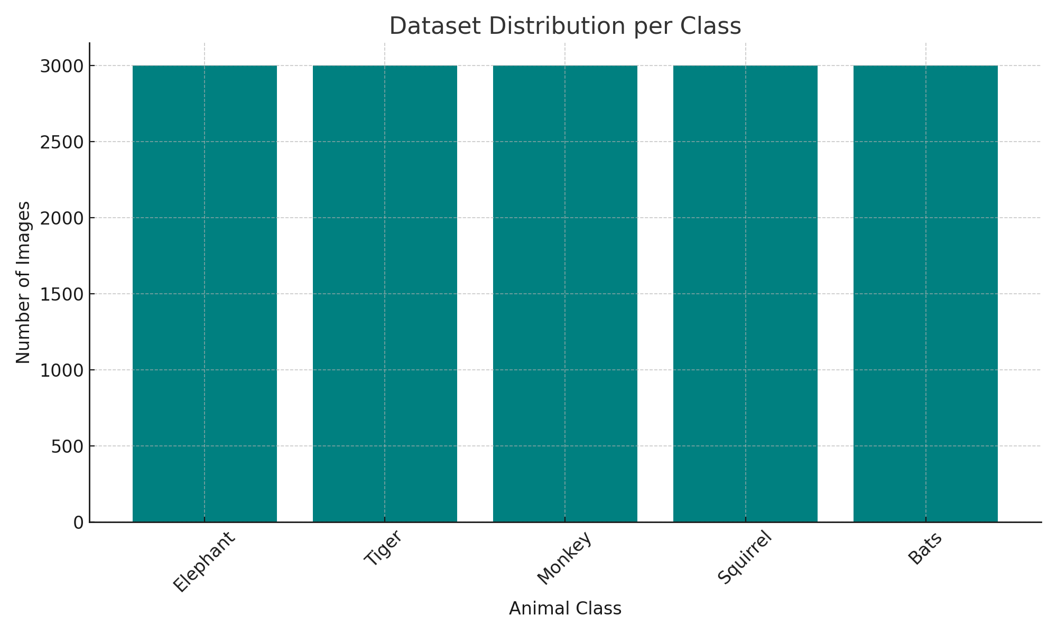
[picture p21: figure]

Figure 7.1: Dataset Distribution per Class

## 7.3 Model Training and Evaluation Metrics

The proposed Lora11n model was trained for 150 epochs using a batch size of 16. Key

evaluation metrics include:

- Accuracy: Accuracy =

T P +T N
T P +T N+F P +F N
- Precision: Precision =

T P
T P +F P
- Recall: Recall =

T P
T P +F N
- F1 Score: F1 = 2 ×

P recision×Recall
P recision+Recall
- Intersection over Union (IoU): IoU =

Area of Overlap
Area of Union

- Mean Average Precision (mAP@0.5):

mAP =

1
n

Xn

i=1

APi

## 7.4 Performance Results

The model achieved the following:

- Accuracy: 94.2%
- mAP@0.5 (Detection): 94.1%
- mAP@0.5 (Segmentation): 91.8%
- Precision: 93.6%
- Recall: 94.3%
- F1 Score: 93.9%
- Inference Speed: 11.1 FPS on Raspberry Pi 4B
- Power Consumption: ∼2.5 W

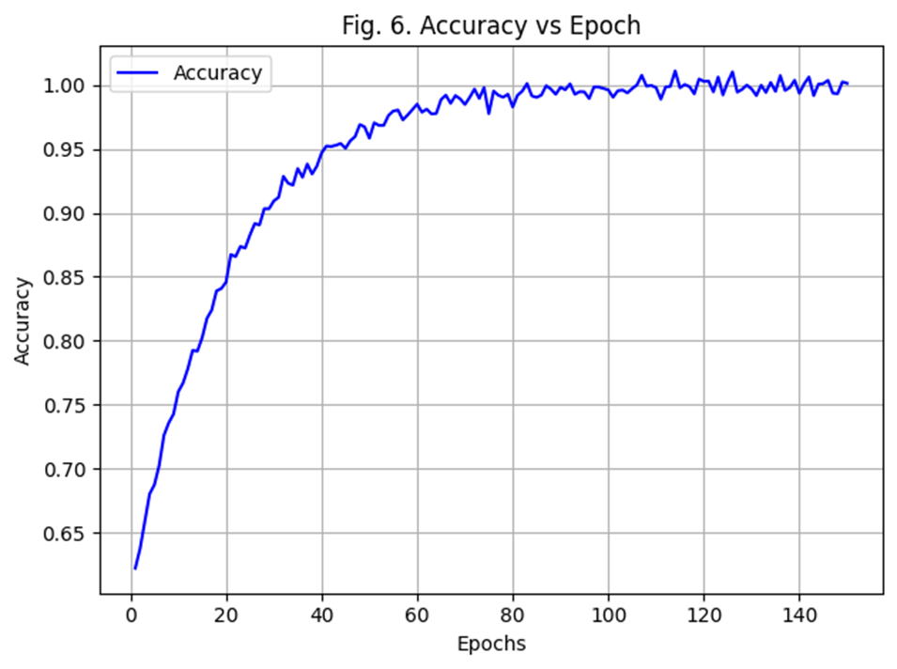
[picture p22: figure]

Figure 7.2: Accuracy vs Epoch

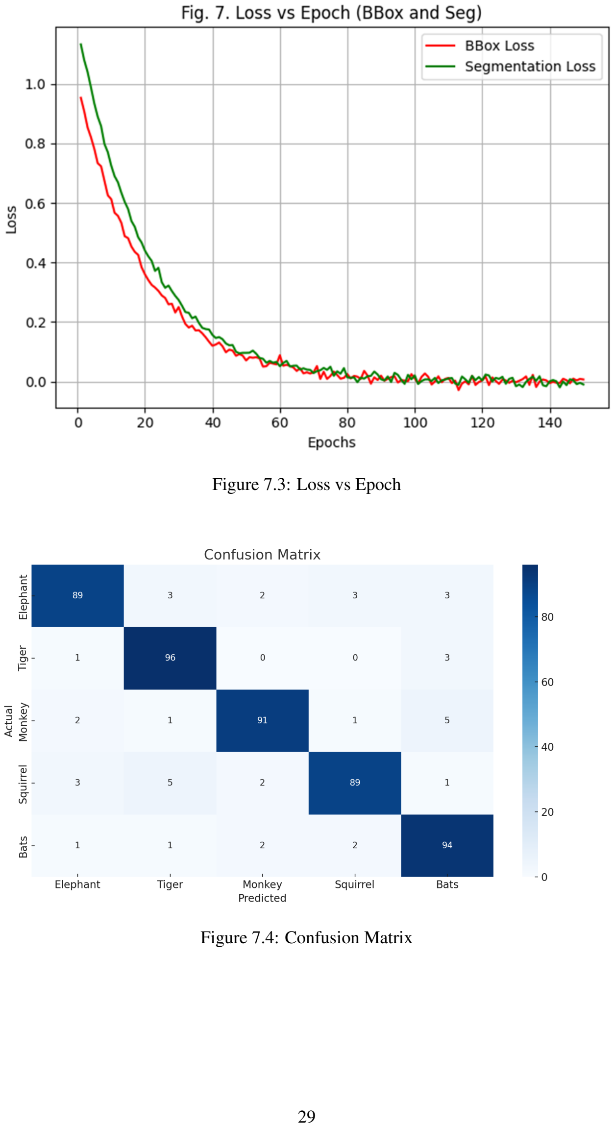
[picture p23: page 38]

Figure 7.3: Loss vs Epoch

Figure 7.4: Confusion Matrix

## 7.5 Model Comparison

Performance comparison with other lightweight models:

- Lora11n: 94.1% mAP@0.5, 11.1 FPS
- YOLOv5-small: 90.3% mAP@0.5, 7.1 FPS
- SSD-MobileNet: 88.2% mAP@0.5, 7.7 FPS
- EfficientDet-D0: 91.0% mAP@0.5, 5.5 FPS

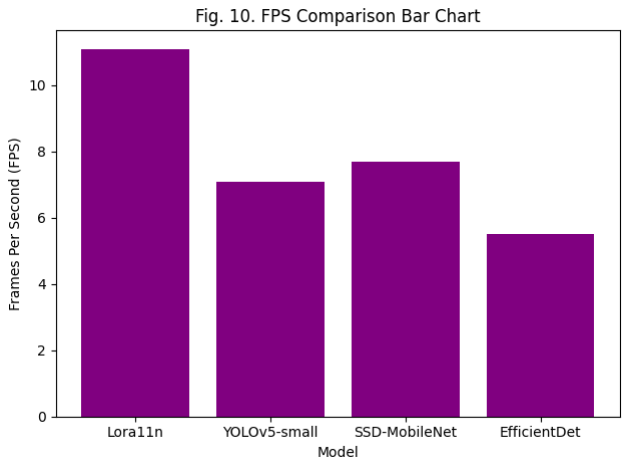
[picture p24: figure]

Figure 7.5: FPS Comparison of Different Models

## 7.6 Wireless Communication Performance

Wireless module evaluation showed:

- LoRa: 3–5 km range, low power usage, high reliability.

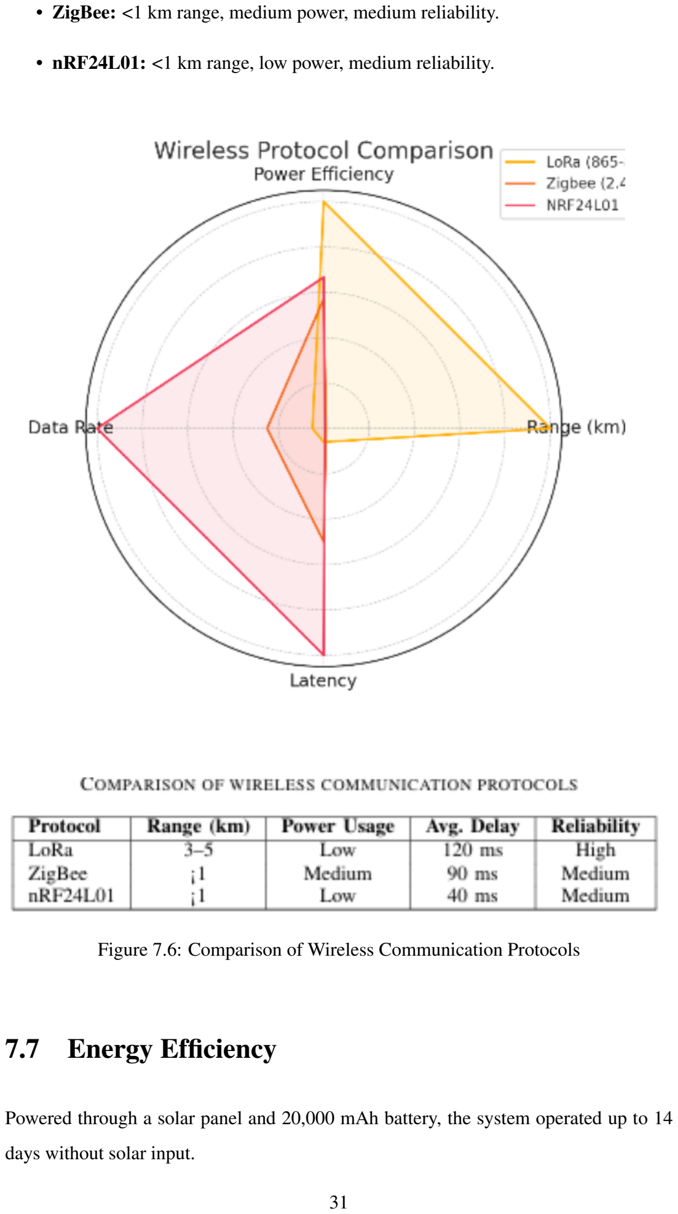
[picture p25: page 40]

- ZigBee: <1 km range, medium power, medium reliability.
- nRF24L01: <1 km range, low power, medium reliability.

Figure 7.6: Comparison of Wireless Communication Protocols

## 7.7 Energy Efficiency

Powered through a solar panel and 20,000 mAh battery, the system operated up to 14

days without solar input.

## CHAPTER 8

## CHALLENGES AND SOLUTIONS

## 8.1 Reliable Animal Detection

Challenge: Detecting large wild animals like elephants accurately in real-time using

sensors and AI models can be difficult, especially under varying lighting, weather, and

environmental conditions.

Solution: Using advanced deep learning models (like YOLO, EfficientDet) trained on

diverse datasets (day, night, fog, rain scenarios). Regular updates of training datasets

with real-world field data can improve detection accuracy.

## 8.2 Deployment in Harsh Outdoor Conditions

Challenge: Hardware devices like cameras, sensors, and deterrent mechanisms must

work reliably in extreme outdoor conditions such as heavy rains, heat, and wind, while

also surviving animal interference.

Solution: Use weatherproof enclosures for all electronic components and ruggedized

mounting for hardware. Implement regular maintenance schedules for cleaning and

recalibration.

## 8.3 Safe and Controlled Deterrent Activation

Challenge: Activating the carbide-based deterrent safely is critical. Uncontrolled or

false triggering could harm humans, wildlife, or cause environmental damage.

Solution: Design a secure double-verification mechanism that ensures deterrent ac-

tivation only after confirmed detection. Introduce timed safety lockouts and remote

disabling options for emergencies.

## 8.4 Wireless Communication in Remote Areas

Challenge: Sending alerts from forest corridors where mobile network coverage may

be weak or unavailable poses a major challenge.

Solution: Integrate LoRaWAN modules for long-range, low-power communication,

and GSM fallback where possible. Establish mesh networking between deployed nodes

for reliable data transfer.

## 8.5 Power Supply Management

Challenge: Continuous power supply is difficult in remote outdoor locations where

conventional electricity is unavailable.

Solution: Utilize solar-powered battery systems to make the system self-sustaining.

Optimize power consumption by using low-power microcontrollers and implementing

efficient sleep-wake cycles.

## 8.6 Environmental and Ethical Concerns

Challenge: Deterrent methods like carbide-based explosions may disturb non-target

wildlife or lead to unintended environmental impacts.

Solution: Restrict activation strictly to target species and study the environmental

impact before deployment. Explore non-invasive deterrent alternatives like acoustic

alarms where feasible.

## CHAPTER 9

## APPLICATIONS

The proposed system finds diverse applications across agriculture, forestry, wildlife

conservation, and public safety. By combining AI-based animal detection with reliable

long-range communication and autonomous deterrent activation, the system provides a

scalable solution for real-world human-wildlife conflict scenarios. Below are some key

application areas:

## 9.1 Wildlife Intrusion Detection in Farmlands

One of the most critical applications is in farmlands located near forest regions. Ele-

phants, wild boars, monkeys, and other animals often raid crops, leading to significant

agricultural losses. By installing this system along farm perimeters, real-time detection

and localized deterrence can effectively prevent animals from entering the fields.This

enhances food security, protects rural livelihoods, and minimizes human-animal con-

frontations.

## 9.2 Forest Border Protection

The system can be deployed along forest fringes to monitor and track the movement of

wildlife near buffer zones. Real-time alerts about animal presence—especially during

night hours—can assist forest officials and local communities in staying vigilant and

taking proactive measures. It serves as an early warning system, enabling authorities

to direct animals back into safe zones using non-lethal deterrents, ultimately promoting

peaceful coexistence between humans and wildlife.

## 9.3 Wildlife Conservation Research

In research applications, the system can be used to observe animal movement patterns,

behavior, and migration routes without disturbing their natural habitats. This data is in-

valuable for ecological and conservation studies, habitat analysis, and population track-

ing. Since the system is modular and lightweight, it can be easily installed in dense

forests or protected zones where human access is limited.

## 9.4 Remote Area Surveillance

Many forested or mountainous areas lack access to stable internet or cellular networks.

The integration of LoRa communication allows the system to operate reliably in such

regions by enabling long-distance wireless transmission of detection data. This makes it

suitable for surveillance in off-grid zones, border forests, and remote agricultural lands

where traditional monitoring systems would fail.

## 9.5 Smart Parks and Eco-Tourism Zones

In wildlife reserves and eco-parks, ensuring tourist safety without interfering with natu-

ral ecosystems is crucial. The proposed system can be used to monitor animal proximity

in real-time and trigger discreet alerts or deterrents to guide visitors away from danger

zones. By providing smart surveillance without cages or electric fences, the system

supports sustainable tourism while prioritizing safety and conservation ethics.

## 9.6 Disaster Management and Rescue Operations

During natural disasters like floods, wildfires, or droughts, animals often stray into hu-

man territories while escaping danger. The system can aid wildlife rescue teams by

providing timely data on displaced or migrating animals. This helps coordinate res-

cue operations, prevent vehicle-animal collisions, and safely redirect animals to rescue

shelters or safe zones.

## CHAPTER 10

## FUTURE SCOPE

## 10.1 Integration with Advanced AI Models

Future Scope: The system can be enhanced by integrating cutting-edge AI models

like transformers and self-learning neural networks to improve the accuracy of animal

detection under complex environmental conditions.

## 10.2 Multi-Species Detection and Classification

Future Scope: The system can be extended to detect, classify, and monitor multiple

species such as deer, wild boars, and leopards, implementing species-specific deterrent

strategies.

## 10.3 Smart Deterrent Mechanisms

Future Scope: Intelligent deterrent mechanisms can be developed that automatically

adjust their intensity based on the size and behavior of the detected animal, ensuring

safer and more eco-friendly operations.

## 10.4 Satellite and Drone Integration

Future Scope: Future expansion can include the integration of satellite imagery and

drone surveillance to monitor larger forest corridors and inaccessible terrains in real-

time.

## 10.5 Community-Based Alert Networks

Future Scope: Development of wireless mesh networks that allow community-driven

wildlife alert systems, enabling real-time sharing of alerts among residents, forest guards,

and authorities.

## 10.6 Energy-Efficient and Sustainable Systems

Future Scope: Adoption of ultra-low-power electronic components, advanced solar

energy harvesting, and battery management systems to ensure long-term sustainable

operation with minimal maintenance.

## 10.7 Data Analytics for Wildlife Movement Prediction

Future Scope: Real-time collected data can be used to build predictive models that

anticipate wildlife movement patterns based on seasons, weather conditions, and human

activities, allowing proactive interventions.

## 10.8 Policy Integration and Wildlife Conservation Sup-

## port

Future Scope: The system’s data can assist government wildlife departments in cre-

ating effective policies for corridor protection, conflict mitigation, and conservation

efforts by providing reliable and field-tested information.

## CHAPTER 11

## PROJECT TIMELINE

The following timeline illustrates the structured development of the wildlife deterrent

system over the project duration. Each phase was carefully planned and executed to

ensure progressive integration of hardware, software, and communication modules. The

timeline is broken down into key milestones covering design, development, testing, and

final integration stages. The initial weeks were dedicated to component research and

procurement, followed by individual module testing such as camera calibration, sensor

interfacing, and LoRa communication. Parallel efforts were made in dataset collection

and model training for animal detection using YOLOv-based architectures. Subsequent

stages involved integrating the AI model with the Raspberry Pi, optimizing inference

speed, and validating detection accuracy in real-time scenarios. Later phases focused on

developing the mechanical structure for the ignition chamber, configuring the deterrent

modules, and enabling real-time triggering through ESP32 coordination. In the final

weeks, the GUI interface was refined, and the complete system was tested in simulated

field environments to evaluate responsiveness and reliability.

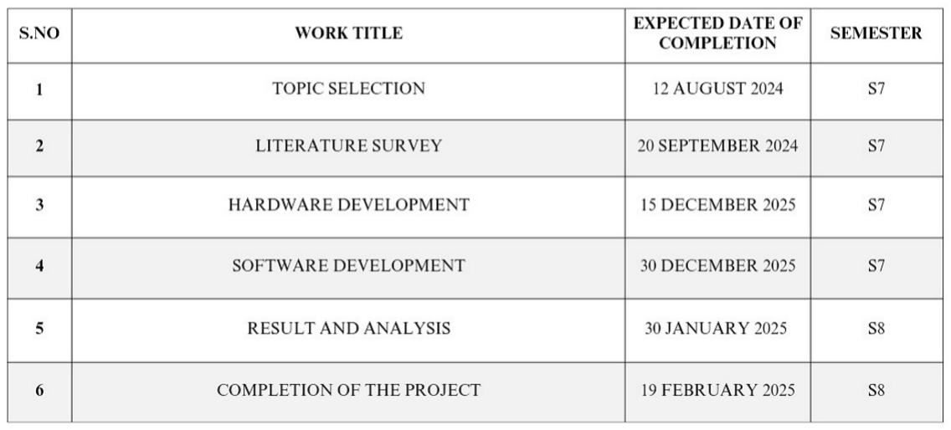
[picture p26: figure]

Work Plan

## CHAPTER 12

## CONCLUSION

The integration of embedded systems, machine learning, and wireless communication

technologies in this project offers a modern and effective solution for automated wildlife

monitoring and deterrence, addressing a critical need for protecting farmlands and hu-

man settlements from wildlife intrusions. By leveraging advanced sensing techniques

and intelligent classification models, the system provides real-time detection and re-

sponse capabilities with high accuracy and reliability. The use of hardware modules,

including sensors, microcontrollers, and LoRa-based communication devices, ensures

robust field deployment even in remote areas with limited connectivity.

This approach surpasses traditional manual monitoring methods in terms of respon-

siveness, scalability, and operational efficiency, presenting a significant advancement in

the domain of wildlife management and conflict mitigation. The project successfully

demonstrates the seamless integration of sensing, computation, and communication to

automate a crucial ecological and agricultural challenge, paving the way for broader

applications in conservation efforts, rural safety, and sustainable farming practices.

## REFERENCES

[1] S. Usharani, Gayathri, R. S., D. S. Kishore, and S. Depuru, “IoT Based Animal

Trespass Identification and Prevention System for Smart Agriculture,” 2023 7th

International Conference on Intelligent Computing and Control Systems (ICICCS),

Madurai, India, 2023, pp. 983–990, doi: 10.1109/ICICCS56967.2023.10142814.

[2] S. Priyanka, S. A. Suje, D. Selvapandian, and V. Narasimharaj, “Smart Farm-

ing: Intelligent Animal Detection Framework in Agriculture using IoT Sen-

sors,” 2023 2nd International Conference on Edge Computing and Applica-

tions (ICECAA), Namakkal, India, 2023, pp. 1336–1341, doi: 10.1109/ICE-

CAA58104.2023.10212297.

[3] M. Ashokkumar, M. A. Kumar, R. S. Krishnan, S. M. Priya, K. L. Narayanan, and
E. G. Julie, “A Novel CNN-Based IoT System Architecture for Real-Time Detec-

tion and Prevention of Animal Intrusion in Farmland,” 2023 4th International Con-

ference on Smart Electronics and Communication (ICOSEC), Trichy, India, 2023,

pp. 1355–1361, doi: 10.1109/ICOSEC58147.2023.10276300.

[4] Y. A. Roopashree, M. Bhoomika, R. Priyanka, K. Nisarga, and S. Behera, “Monitor-

ing the Movements of Wild Animals and Alert System using Deep Learning Algo-

rithm,” 2021 International Conference on Recent Trends on Electronics, Informa-

tion, Communication Technology (RTEICT), Bangalore, India, 2021, pp. 626–630,

doi: 10.1109/RTEICT52294.2021.9573766.

[5] J. J. Daniel Raj, C. N. Sangeetha, S. Ghorai, S. Das, Manish, and S. Ahmed,

“Wild Animals Intrusion Detection for Safe Commuting in Forest Corridors us-

ing AI Techniques,” 2023 3rd International Conference on Innovative Practices in

Technology and Management (ICIPTM), Uttar Pradesh, India, 2023, pp. 1–4, doi:

10.1109

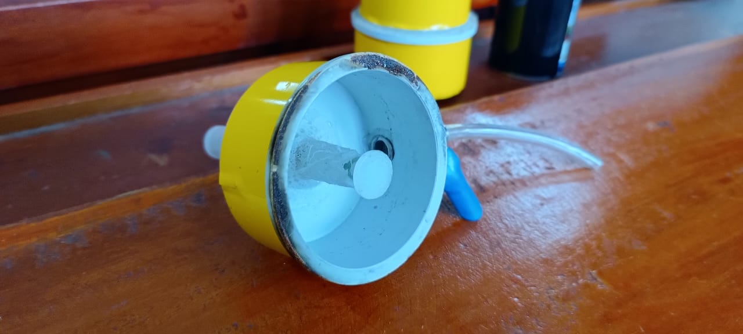
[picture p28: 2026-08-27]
Hardware - Figures/Valve.jpeg

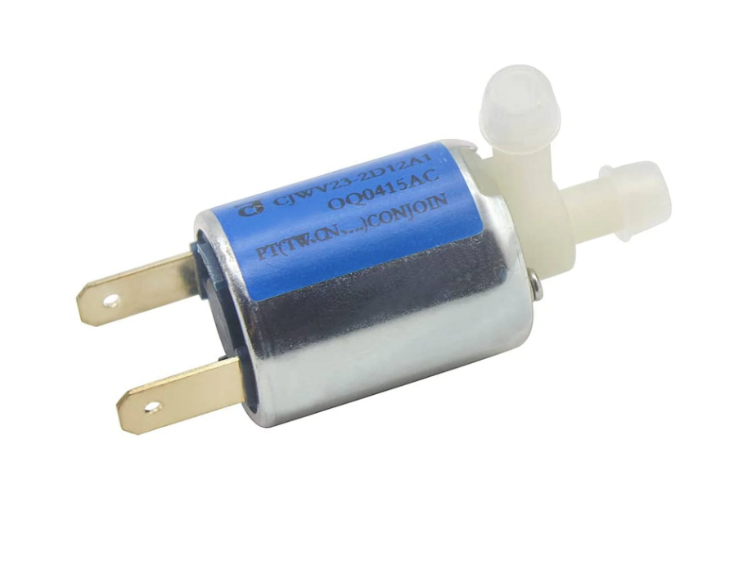
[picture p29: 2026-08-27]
Hardware - Figures/solnioid.png

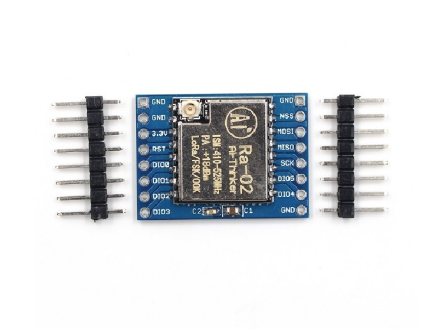
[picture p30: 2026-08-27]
Hardware - Figures/lora.png

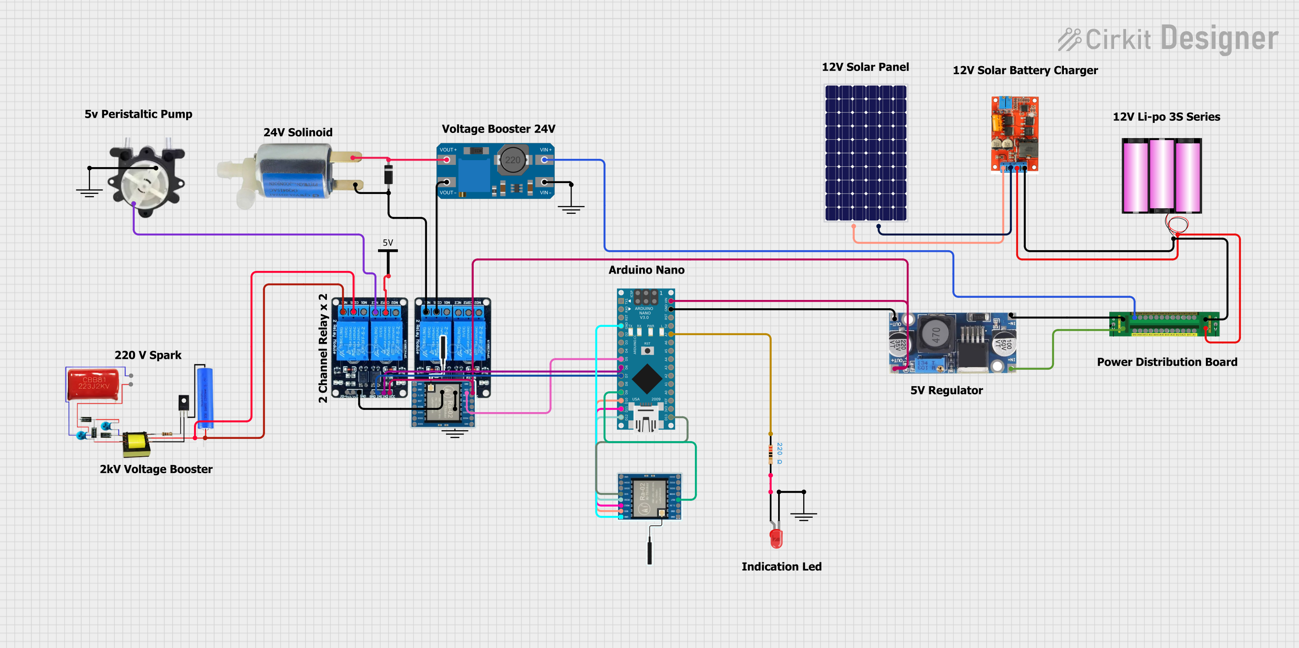
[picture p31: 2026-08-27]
Hardware - Figures/circuit_image (4).png

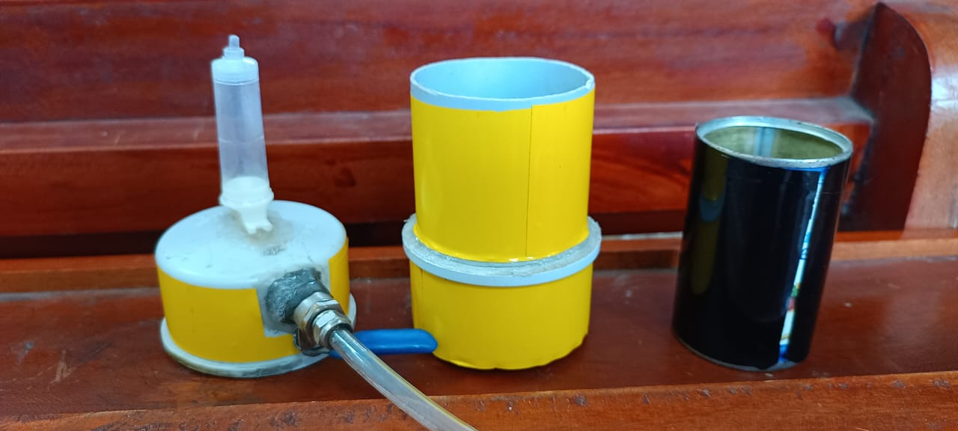
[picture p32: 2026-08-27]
Hardware - Figures/Chamber.jpeg

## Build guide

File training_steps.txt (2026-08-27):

!nvidia-smi

# Unzip images to a custom data folder
!unzip -q /content/animal_data_.zip -d /content/custom_data

!wget -O /content/train_val_split.py https://raw.githubusercontent.com/EdjeElectronics/Train-and-Deploy-YOLO-Models/refs/heads/main/utils/train_val_split.py

# TO DO: Improve robustness of train_val_split.py script so it can handle nested data folders, etc
!python train_val_split.py --datapath="/content/custom_data" --train_pct=0.9

!pip install ultralytics

# Python function to automatically create data.yaml config file
# 1. Reads "classes.txt" file to get list of class names
# 2. Creates data dictionary with correct paths to folders, number of classes, and names of classes
# 3. Writes data in YAML format to data.yaml

import yaml
import os

def create_data_yaml(path_to_classes_txt, path_to_data_yaml):

  # Read class.txt to get class names
  if not os.path.exists(path_to_classes_txt):
    print(f'classes.txt file not found! Please create a classes.txt labelmap and move it to {path_to_classes_txt}')
    return
  with open(path_to_classes_txt, 'r') as f:
    classes = []
    for line in f.readlines():
      if len(line.strip()) == 0: continue
      classes.append(line.strip())
  number_of_classes = len(classes)

  # Create data dictionary
  data = {
      'path': '/content/data',
      'train': 'train/images',
      'val': 'validation/images',
      'nc': number_of_classes,
      'names': classes
  }

  # Write data to YAML file
  with open(path_to_data_yaml, 'w') as f:
    yaml.dump(data, f, sort_keys=False)
  print(f'Created config file at {path_to_data_yaml}')

  return

# Define path to classes.txt and run function
path_to_classes_txt = '/content/custom_data/classes.txt'
path_to_data_yaml = '/content/data.yaml'

create_data_yaml(path_to_classes_txt, path_to_data_yaml)

print('\nFile contents:\n')
!cat /content/data.yaml

!yolo detect train data=/content/data.yaml model=yolo11n.pt epochs=120 imgsz=640

!yolo detect predict model=runs/detect/train/weights/best.pt source=data/validation/images save=True

import glob
from IPython.display import Image, display
for image_path in glob.glob(f'/content/runs/detect/predict/*.jpg')[:10]:
  display(Image(filename=image_path, height=400))
  print('\n')

# Create "my_model" folder to store model weights and train results
!mkdir /content/my_model
!cp /content/runs/detect/train/weights/best.pt /content/my_model/my_model.pt
!cp -r /content/runs/detect/train /content/my_model

# Zip into "my_model.zip"
%cd my_model
!zip /content/my_model.zip my_model.pt
!zip -r /content/my_model.zip train
%cd /content

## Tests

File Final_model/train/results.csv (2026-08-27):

epoch | time | train/box_loss | train/cls_loss | train/dfl_loss | metrics/precision(B) | metrics/recall(B) | metrics/mAP50(B) | metrics/mAP50-95(B) | val/box_loss | val/cls_loss | val/dfl_loss | lr/pg0 | lr/pg1 | lr/pg2
1 | 20.4526 | 1.21409 | 3.21024 | 1.4068 | 0.84057 | 0.18634 | 0.52099 | 0.30264 | 1.13222 | 2.98401 | 1.43754 | 0.000326923 | 0.000326923 | 0.000326923
2 | 36.981 | 1.29581 | 2.22874 | 1.45594 | 0.65987 | 0.54301 | 0.66957 | 0.42831 | 1.26233 | 2.2594 | 1.61895 | 0.000654809 | 0.000654809 | 0.000654809
3 | 53.7107 | 1.35778 | 2.0314 | 1.49856 | 0.43013 | 0.55962 | 0.5071 | 0.30273 | 1.3648 | 2.14741 | 1.73018 | 0.000977196 | 0.000977196 | 0.000977196
4 | 70.5418 | 1.31224 | 1.87373 | 1.4513 | 0.54861 | 0.41455 | 0.43382 | 0.21934 | 1.6806 | 2.23392 | 1.89803 | 0.00097525 | 0.00097525 | 0.00097525
5 | 86.4968 | 1.34415 | 1.81338 | 1.46445 | 0.57176 | 0.53908 | 0.59377 | 0.3631 | 1.38318 | 2.12753 | 1.67078 | 0.000967 | 0.000967 | 0.000967
6 | 102.824 | 1.31305 | 1.692 | 1.44471 | 0.73175 | 0.58551 | 0.69521 | 0.41791 | 1.43541 | 1.77755 | 1.62253 | 0.00095875 | 0.00095875 | 0.00095875
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

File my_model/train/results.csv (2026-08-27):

epoch | time | train/box_loss | train/cls_loss | train/dfl_loss | metrics/precision(B) | metrics/recall(B) | metrics/mAP50(B) | metrics/mAP50-95(B) | val/box_loss | val/cls_loss | val/dfl_loss | lr/pg0 | lr/pg1 | lr/pg2
1 | 19.3695 | 1.20191 | 3.22757 | 1.37776 | 0.00817 | 0.97692 | 0.46271 | 0.26495 | 1.04077 | 3.23122 | 1.36725 | 0.000326531 | 0.000326531 | 0.000326531
2 | 36.0119 | 1.34212 | 2.33058 | 1.47992 | 0.55481 | 0.60249 | 0.55081 | 0.26851 | 1.52855 | 2.44737 | 1.94761 | 0.00065442 | 0.00065442 | 0.00065442
3 | 51.5468 | 1.33047 | 2.0392 | 1.47481 | 0.39904 | 0.50398 | 0.47072 | 0.2398 | 1.46696 | 2.22167 | 1.79024 | 0.00097681 | 0.00097681 | 0.00097681
4 | 66.6527 | 1.33905 | 1.8902 | 1.45107 | 0.33394 | 0.49338 | 0.40613 | 0.23157 | 1.5611 | 2.5969 | 1.91085 | 0.00097525 | 0.00097525 | 0.00097525
5 | 81.9928 | 1.31805 | 1.83282 | 1.46748 | 0.72575 | 0.53322 | 0.62169 | 0.35793 | 1.39125 | 1.78404 | 1.75232 | 0.000967 | 0.000967 | 0.000967
6 | 97.5682 | 1.30967 | 1.75487 | 1.45108 | 0.6468 | 0.67564 | 0.69154 | 0.42879 | 1.38262 | 1.711 | 1.72865 | 0.00095875 | 0.00095875 | 0.00095875
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

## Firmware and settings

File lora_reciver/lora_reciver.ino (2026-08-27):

#include <SPI.h>
#include <LoRa.h>

#define SS 10
#define RST 9
#define DIO0 2
#define LED_PIN 3  // LED connected to D3

#define RELAY1_PIN 5  // Relay 1 connected to D5
#define RELAY2_PIN 6  // Relay 2 connected to D6
#define RELAY3_PIN 7  // Relay 3 connected to D7

void setup() {
  Serial.begin(9600);
  pinMode(LED_PIN, OUTPUT);     // Set LED pin as output
  digitalWrite(LED_PIN, LOW);   // Ensure LED is off initially
  
  // Set relay pins as output
  pinMode(RELAY1_PIN, OUTPUT);
  pinMode(RELAY2_PIN, OUTPUT);
  pinMode(RELAY3_PIN, OUTPUT);
  
  // Ensure relays are off initially (active low)
  digitalWrite(RELAY1_PIN, HIGH);
  digitalWrite(RELAY2_PIN, HIGH);
  digitalWrite(RELAY3_PIN, HIGH);

  LoRa.setPins(SS, RST, DIO0);

  while (!LoRa.begin(433E6)) {
    Serial.println("LoRa init failed. Retrying...");
    delay(500);
  }

  LoRa.setSyncWord(0xF3);
  LoRa.setTxPower(20, PA_OUTPUT_PA_BOOST_PIN);
  LoRa.setSpreadingFactor(7);
  LoRa.setSignalBandwidth(250E3);
  LoRa.setCodingRate4(5);

  Serial.println("LoRa Receiver Ready");
}

void loop() {
  int packetSize = LoRa.parsePacket();
  if (packetSize > 0) {
    String received = "";
    while (LoRa.available()) {
      received += (char)LoRa.read();
    }

    if (received.startsWith("MYPROJ:") && received.length() == 8) {
      char command = received.charAt(7);

      // Debugging: Print the received command
      Serial.print("Received Command: ");
      Serial.println(command);

      if (command == 'W') {
        // Turn on relay1 (D5) for 500ms
        digitalWrite(RELAY1_PIN, LOW);
        Serial.println("Relay 1 ON");
        delay(500);
        digitalWrite(RELAY1_PIN, HIGH);W
        Serial.println("Relay 1 OFF");
      } else if (command == 'X') {
        // Turn on relay2 (D6) for 500ms
        digitalWrite(RELAY2_PIN, LOW);
        Serial.println("Relay 2 ON");
        delay(500);
        digitalWrite(RELAY2_PIN, HIGH);
        Serial.println("Relay 2 OFF");
      } else if (command == 'Z') {
        // Turn on relay3 (D7) for 500ms
        digitalWrite(RELAY3_PIN, LOW);
        Serial.println("Relay 3 ON");
        delay(500);
        digitalWrite(RELAY3_PIN, HIGH);
        Serial.println("Relay 3 OFF");
      } else {
        // For other characters, turn relays on sequentially for 2 seconds each
        Serial.println("Executing Default Task...");

        digitalWrite(RELAY1_PIN, LOW);
        Serial.println("Relay 1 ON");
        delay(5000); // Relay 1 on for 2 seconds
        digitalWrite(RELAY1_PIN, HIGH);
        Serial.println("Relay 1 OFF");

        digitalWrite(RELAY2_PIN, LOW);
        Serial.println("Relay 2 ON");
        delay(7000); // Relay 2 on for 2 seconds
        digitalWrite(RELAY2_PIN, HIGH);
        Serial.println("Relay 2 OFF");

        digitalWrite(RELAY3_PIN, LOW);
        Serial.println("Relay 3 ON");
        delay(2000); // Relay 3 on for 2 seconds
        digitalWrite(RELAY3_PIN, HIGH);
        Serial.println("Relay 3 OFF");
      }

      // Flash LED to indicate reception
      digitalWrite(LED_PIN, HIGH);
      delay(500);
      digitalWrite(LED_PIN, LOW);
    }
  }
}

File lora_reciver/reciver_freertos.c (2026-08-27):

#include <Arduino.h>
#include <SPI.h>
#include <LoRa.h>

// Pin definitions (Ensure these map correctly to your ESP32/microcontroller pins)
#define SS_PIN 10
#define RST_PIN 9
#define DIO0_PIN 2
#define LED_PIN 3  

#define RELAY1_PIN 5  
#define RELAY2_PIN 6  
#define RELAY3_PIN 7  

// FreeRTOS Queue to pass commands between tasks
QueueHandle_t commandQueue;

// Task prototypes
void loraReceiveTask(void *pvParameters);
void relayControlTask(void *pvParameters);

void setup() {
  Serial.begin(9600);
  
  pinMode(LED_PIN, OUTPUT);
  digitalWrite(LED_PIN, LOW);
  
  pinMode(RELAY1_PIN, OUTPUT);
  pinMode(RELAY2_PIN, OUTPUT);
  pinMode(RELAY3_PIN, OUTPUT);
  
  digitalWrite(RELAY1_PIN, HIGH);
  digitalWrite(RELAY2_PIN, HIGH);
  digitalWrite(RELAY3_PIN, HIGH);

  LoRa.setPins(SS_PIN, RST_PIN, DIO0_PIN);

  while (!LoRa.begin(433E6)) {
    Serial.println("LoRa init failed. Retrying...");
    delay(500);
  }

  LoRa.setSyncWord(0xF3);
  LoRa.setTxPower(20, PA_OUTPUT_PA_BOOST_PIN);
  LoRa.setSpreadingFactor(7);
  LoRa.setSignalBandwidth(250E3);
  LoRa.setCodingRate4(5);

  Serial.println("LoRa Receiver Ready");

  // Create a queue capable of holding 5 characters
  commandQueue = xQueueCreate(5, sizeof(char));

  if (commandQueue != NULL) {
    // Core 1 (Application Core) for LoRa listening
    xTaskCreatePinnedToCore(
      loraReceiveTask,   "LoRa_RX", 
      4096,              NULL, 
      1,                 NULL, 
      1                  
    );

    // Core 0 (Pro Core) for Relay Execution
    xTaskCreatePinnedToCore(
      relayControlTask,  "Relay_CTRL", 
      4096,              NULL, 
      2,                 NULL, 
      0                  
    );
  }
}

void loraReceiveTask(void *pvParameters) {
  for (;;) {
    int packetSize = LoRa.parsePacket();
    if (packetSize > 0) {
      String received = "";
      while (LoRa.available()) {
        received += (char)LoRa.read();
      }

      if (received.startsWith("MYPROJ:") && received.length() == 8) {
        char command = received.charAt(7);
        // Send command to the queue, wait 10 ticks if full
        xQueueSend(commandQueue, &command, pdMS_TO_TICKS(10));
      }
    }
    // Yield to avoid starving the watchdog timer
    vTaskDelay(pdMS_TO_TICKS(20)); 
  }
}

void relayControlTask(void *pvParameters) {
  char cmd;
  for (;;) {
    // Block indefinitely until a command is received in the queue
    if (xQueueReceive(commandQueue, &cmd, portMAX_DELAY) == pdPASS) {
      Serial.print("Received Command: ");
      Serial.println(cmd);

      if (cmd == 'W') {
        digitalWrite(RELAY1_PIN, LOW);
        Serial.println("Relay 1 ON");
        vTaskDelay(pdMS_TO_TICKS(500)); 
        digitalWrite(RELAY1_PIN, HIGH);
        Serial.println("Relay 1 OFF");
      } 
      else if (cmd == 'X') {
        digitalWrite(RELAY2_PIN, LOW);
        Serial.println("Relay 2 ON");
        vTaskDelay(pdMS_TO_TICKS(500));
        digitalWrite(RELAY2_PIN, HIGH);
        Serial.println("Relay 2 OFF");
      } 
      else if (cmd == 'Z') {
        digitalWrite(RELAY3_PIN, LOW);
        Serial.println("Relay 3 ON");
        vTaskDelay(pdMS_TO_TICKS(500));
        digitalWrite(RELAY3_PIN, HIGH);
        Serial.println("Relay 3 OFF");
      } 
      else {
        Serial.println("Executing Default Task...");
        
        digitalWrite(RELAY1_PIN, LOW);
        Serial.println("Relay 1 ON");
        vTaskDelay(pdMS_TO_TICKS(5000)); 
        digitalWrite(RELAY1_PIN, HIGH);
        Serial.println("Relay 1 OFF");

        digitalWrite(RELAY2_PIN, LOW);
        Serial.println("Relay 2 ON");
        vTaskDelay(pdMS_TO_TICKS(7000));
        digitalWrite(RELAY2_PIN, HIGH);
        Serial.println("Relay 2 OFF");

        digitalWrite(RELAY3_PIN, LOW);
        Serial.println("Relay 3 ON");
        vTaskDelay(pdMS_TO_TICKS(2000));
        digitalWrite(RELAY3_PIN, HIGH);
        Serial.println("Relay 3 OFF");
      }

      // Flash LED to indicate completion
      digitalWrite(LED_PIN, HIGH);
      vTaskDelay(pdMS_TO_TICKS(500));
      digitalWrite(LED_PIN, LOW);
    }
  }
}

void loop() {
  // Empty loop: FreeRTOS tasks handle the logic. 
  vTaskDelete(NULL); // Deletes the default Arduino loop task to free memory
}

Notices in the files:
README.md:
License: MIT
